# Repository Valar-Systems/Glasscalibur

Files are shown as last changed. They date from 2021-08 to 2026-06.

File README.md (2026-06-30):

# Glasscalibur — Automated Horizontal Window Opener

Glasscalibur is a smart opener for horizontal-sliding windows. A NEMA stepper
motor drives a lead screw that slides your window open and closed, controlled by
an ESP32‑C6 running [ESPHome](https://esphome.io). Control it from **any web
browser** with no app and no cloud account, pair it natively with **Home
Assistant**, or automate it with schedules, sunrise/sunset, or any system that
can send an HTTP request (Node‑RED, scripts, IFTTT‑style webhooks, etc.).

window opener main

> The video above has the top cover removed so you can see the mechanism. Under
> the cover, a custom PCB with an **ESP32‑C6** and a **TMC2209** stepper driver
> runs the motor; **limit switches** at each end of travel give the cover an
> absolute, self‑correcting position.

window opener top

---

## Features

- **Browser control, no cloud** — open `http://glasscalibur-XXXXXX.local` on
  your network and drive the cover, tune the motor, and set schedules. No Home
  Assistant or account required.
- **Native Home Assistant** — auto‑discovered over the ESPHome API as a real
  cover entity (no `command_line`/curl glue).
- **Built‑in scheduling** — open/close at fixed times **or** at sunrise/sunset
  (with minute offsets), all editable from the browser. Survives reboots.
- **Obstruction & stall protection** — TMC2209 **StallGuard** plus an
  accelerometer‑based **vibration‑stall** backstop stop the motor when the
  window jams, is locked, or something gets in the way, and save the position.
- **Over‑temperature cutoff** — an on‑board temperature sensor stops the motor
  if it exceeds 80 °C.
- **Anti‑tamper alarm** — the accelerometer flags if a mounted unit is moved or
  tilted and sounds a buzzer.
- **Over‑the‑air updates** — a one‑click **Update Firmware** button pulls the
  latest release straight from GitHub. No computer needed.
- **Instant manual override** — the whole device lifts off the window in a
  couple of seconds for cleaning or emergencies (see GIF below).

---

## How it works

Glasscalibur uses a **NEMA 17 stepper motor** connected to a **lead screw**. As
the screw turns, a nut travels along it and pushes/pulls the window sash. A
custom PCB with an **ESP32‑C6‑MINI** and a **TMC2209** silent stepper driver
runs the motor over a single‑wire UART link.

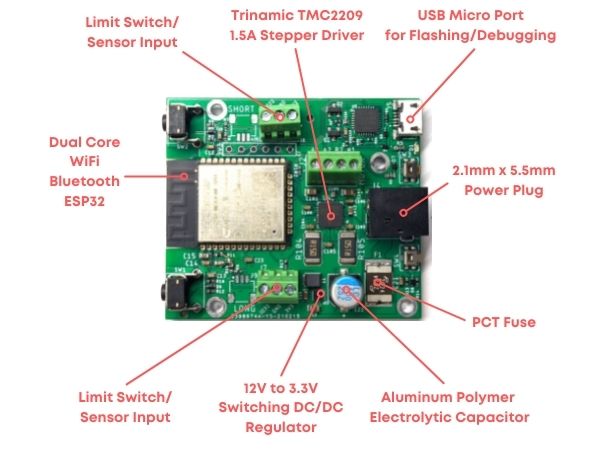
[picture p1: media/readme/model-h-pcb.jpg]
window opener PCB


Two **limit switches** — one at each end of travel — give the cover a known
absolute position: every time the carriage hits a limit, the firmware
re‑calibrates its step count, so position never drifts. The board also carries:

- a **TMP1075** temperature sensor (motor over‑temp cutoff),
- a **LIS2DH12** 3‑axis accelerometer (vibration‑stall + anti‑tamper),
- a **piezo buzzer** (tamper alarm), and
- physical buttons (a control button and a Wi‑Fi‑reset button).

The firmware is a single ESPHome configuration — see
[`firmware/esphome/`](/firmware/esphome) for the full, heavily commented config
and a flashing guide.

---

## Safety features

Safety is the primary concern with this device.

**Instant removal.** In an emergency the entire device lifts straight off the
window — no tools, a couple of seconds.

instant removal

**Obstruction & lock detection.** While moving, the cover watches for a stall
two ways: the TMC2209's StallGuard reads the motor's mechanical load, and the
accelerometer watches for the hard vibration a jammed mechanism produces. If
something gets in the way, or the window is locked, the motor stops and saves
its position. Both detectors have adjustable sensitivity so you can tune them to
your window.

**Over‑temperature cutoff.** If the motor sensor reads above 80 °C, motion stops
automatically.

**Anti‑tamper.** Once armed, the accelerometer learns the device's resting
orientation; if a mounted unit is bumped, tilted, or pried, it raises a Tamper
alert and sounds the buzzer.

---

## Will it work on your window?

Before you build or buy, check that the device fits your window. Window **sill
height** is the main factor.

### Is your window sill the correct height?

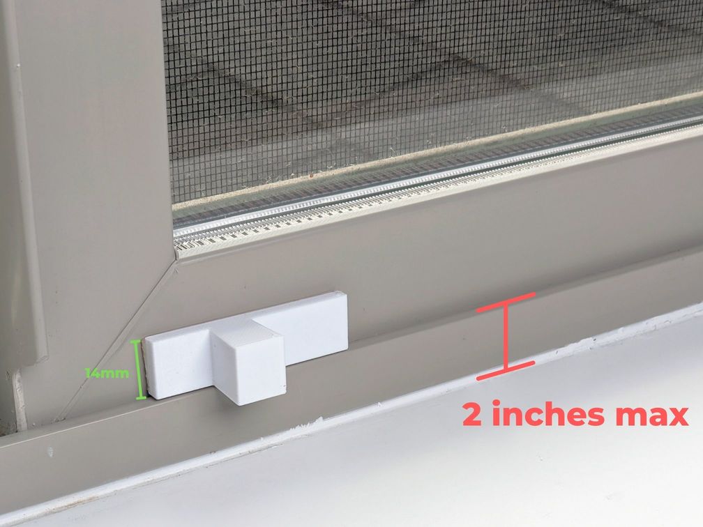
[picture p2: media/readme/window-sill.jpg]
window sill


The maximum distance from the top of the window frame to the sill is **2 inches**
(red text above). More than that and you'll need to raise the opener — a piece
of wood such as a 1×4 or 2×4 under the whole device works well.

To attach the window mount (white piece above), you need **14 mm** of the lower
sash exposed.

### Is your window wide enough?

The device is just under **22 in** end to end, so your window needs to be at
least **44 in** wide — add 2 in to be safe, so target **46 in**.

### Is your window too heavy?

The motor has been tested up to **40 lb** of window. That's very heavy and can
cause problems; if your window is that heavy, lubricate the track with dry
silicone spray first and see if that helps.

---

## Controlling it

You have several options, and they all work at once:

| Method | How |
| --- | --- |
| **Web browser** | Open `http://glasscalibur-XXXXXX.local` (the `XXXXXX` MAC suffix is printed on the USB serial log at boot). Full control panel — cover, motor tuning, schedule, diagnostics. |
| **Home Assistant** | The device is auto‑discovered over the native ESPHome API as a `cover` entity. No YAML, no curl. |
| **HTTP / REST** | The ESPHome web server exposes a REST API, e.g. `POST http://glasscalibur-XXXXXX.local/cover/glasscalibur/set?position=0.5` (position is `0.0`=closed … `1.0`=open), and `/open`, `/close`, `/stop`. Drive it from Node‑RED, scripts, or webhooks. |

### Scheduling

Two browser‑editable modes, gated by a master **Schedule Enabled** switch:

- **Fixed times** — set an **Open Time** and **Close Time**.
- **Sunrise/sunset** — turn on **Sun Schedule**, set your **latitude/longitude**,
  and optionally an open/close **offset** in minutes (e.g. `-30` to close 30 min
  before sunset).

### Home automation ideas

Home automation is where this device shines:

1. Use an indoor air‑quality sensor (e.g. Awair) to air out a stuffy room.
2. Poll PurpleAir hourly and close the window when outdoor air goes bad.
3. Compare indoor/outdoor temperature and cool the room when it helps.
4. Check a weather API and close the window when rain is forecast.
5. Open at sunrise to wake up to the birds.

Full step‑by‑step guides for all of the above live in the
[**project wiki**](https://github.com/Valar-Systems/Glasscalibur/wiki).

---

## Repository layout

| Path | Contents |
| --- | --- |
| [`firmware/esphome/`](/firmware/esphome) | **Current firmware** — the ESPHome config (`Glasscalibur-esphome.yml`) and a flashing/release guide. |
| [`firmware/arduino/`](/firmware/arduino) | Legacy Arduino firmware (the original ESPUI/HTTP build). Kept for reference. |
| [`hardware/v2.0/`](/hardware/v2.0) | 3D‑printable parts — STEP CAD files plus a ready‑to‑slice print platter (`platter-v1.3mf`). |
| [`media/`](/media) | Images and GIFs used in the docs. |

---

## How to build it

To keep it affordable, there's a kit — sourcing the screws and hardware
individually gets expensive fast.

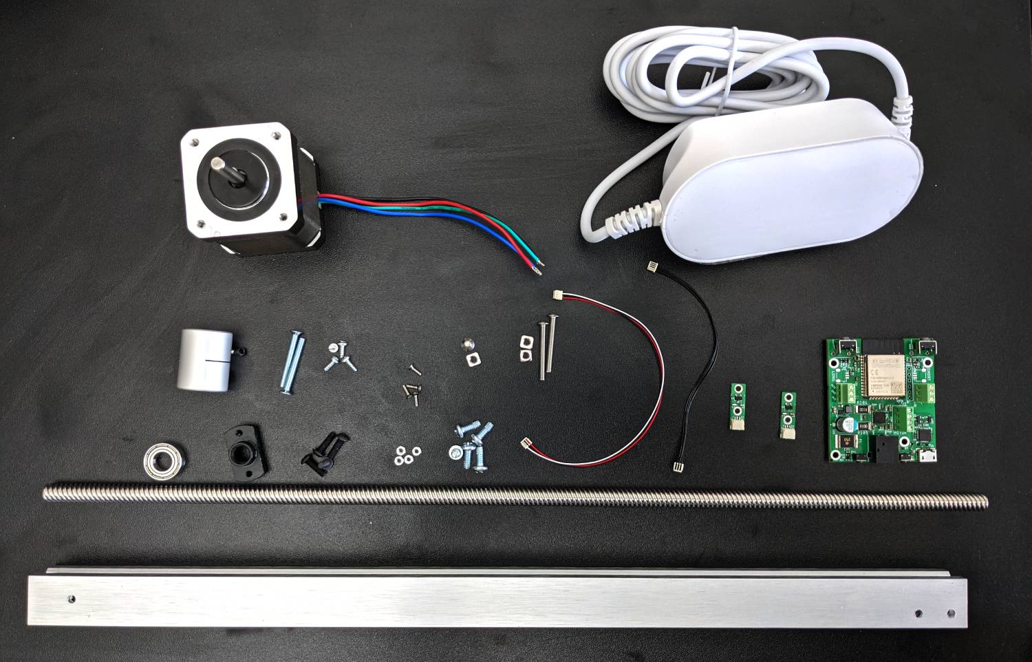
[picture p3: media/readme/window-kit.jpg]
window kit


Two kit versions are available — one with the 3D‑printed plastics and one
without (print your own):

- [Kit **excluding** 3D‑printed parts](https://valarsystems.com/products/automatic-window-opener?variant=39590892240955)
- [Kit **including** 3D‑printed parts](https://valarsystems.com/products/automatic-window-opener?variant=39590892208187)

Full assembly instructions and a build video are in the
[**Assembly Guide**](https://github.com/Valar-Systems/Glasscalibur/wiki/Assembly-Guide).

## How to 3D print it

The printable parts are in [`hardware/v2.0/`](/hardware/v2.0):

- **`platter-v1.3mf`** — a ready‑to‑slice [PrusaSlicer](https://www.prusa3d.com/prusaslicer/)
  project with the parts laid out on the bed. Print in **PETG** at **0.25 mm**
  layer height.
- The individual **`.step`** files are the CAD source for each part if you want
  to modify or re‑orient them.

See the [**3D Printing Guide**](https://github.com/Valar-Systems/Glasscalibur/wiki/3D-Printing-Guide)
for details.

## How to install it

Installation is **fast** — a few minutes of work, then a 24‑hour wait for the
adhesive to cure.

window mount

1. Attach the **window mount** (to the sash).
2. Attach the **sill mount**.
3. Wait **24 hours** for the adhesives to set, then start using the opener.

Both mounts are adhesive; if needed you can add a screw into the sill, but that
hasn't been required. Full details are in the
[**Window Installation Guide**](https://github.com/Valar-Systems/Glasscalibur/wiki/Installation-Guide).

---

## Firmware: flashing & updates

- **First flash** of a blank board is over **USB** with the ESPHome CLI
  (`esphome run firmware/esphome/Glasscalibur-esphome.yml`) or via
  [web.esphome.io](https://web.esphome.io).
- After that, update **over the air**: open the web UI → **Diagnostics** →
  **Update Firmware (GitHub)**, and the device pulls the
  [latest release](https://github.com/Valar-Systems/Glasscalibur/releases/latest)
  and reflashes itself.

The build, release, and OTA process is documented in
[`firmware/esphome/README.md`](/firmware/esphome/README.md).

---

## Documentation

The [**project wiki**](https://github.com/Valar-Systems/Glasscalibur/wiki) has
the full guides:

- [3D Printing](https://github.com/Valar-Systems/Glasscalibur/wiki/3D-Printing-Guide)
- [Assembly](https://github.com/Valar-Systems/Glasscalibur/wiki/Assembly-Guide)
- [Window Installation](https://github.com/Valar-Systems/Glasscalibur/wiki/Installation-Guide)
- [Wi‑Fi Setup](https://github.com/Valar-Systems/Glasscalibur/wiki/WiFi-Setup)
- [Web UI](https://github.com/Valar-Systems/Glasscalibur/wiki/Web-UI-Guide)
- [Motor & Stall Tuning](https://github.com/Valar-Systems/Glasscalibur/wiki/Motor-Setup)
- [Scheduling](https://github.com/Valar-Systems/Glasscalibur/wiki/Scheduling-Guide)
- [Security & Tamper](https://github.com/Valar-Systems/Glasscalibur/wiki/Security-and-Tamper)
- [API](https://github.com/Valar-Systems/Glasscalibur/wiki/API-Guide)
- [Home Assistant](https://github.com/Valar-Systems/Glasscalibur/wiki/Home-Assistant-Guide)
- [Firmware Updates](https://github.com/Valar-Systems/Glasscalibur/wiki/Firmware-Updates)

---

## License

The firmware is licensed under the **GNU GPL v3** — see
[`firmware/LICENSE`](/firmware/LICENSE).

If this project is useful to you, you can support it via
[GitHub Sponsors](https://github.com/sponsors/valar-systems).

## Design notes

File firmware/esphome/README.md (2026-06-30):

# Glasscalibur — ESPHome firmware

Wi-Fi window-cover controller (ESP32-C6 + TMC2209 stepper). Control it from any
browser at `http://glasscalibur-XXXXXX.local` (no Home Assistant required), or
pair it with Home Assistant over the native ESPHome API.

The full config lives in [`Glasscalibur-esphome.yml`](Glasscalibur-esphome.yml);
every setting is documented inline in that file.

## Web UI

Open `http://glasscalibur-XXXXXX.local` (the `XXXXXX` MAC suffix is printed on
the serial log at boot). Entities are organized into collapsible groups:

| Group | What's in it |
| --- | --- |
| **Control** | The cover, its live State, and Button 1 |
| **Motion Tuning** | Speed, acceleration, IRUN (motor current) |
| **StallGuard / Stall Detection** | StallGuard + the accelerometer vibration-stall backstop and their thresholds |
| **Security / Tamper** | Tamper detection, threshold, baseline / clear buttons |
| **Schedule** | Fixed open/close times **or** sunrise/sunset, timezone, location |
| **Diagnostics** | Firmware version, **Update Firmware**, **Restart**, temps, Wi-Fi, lifetime counters |

## Scheduling

Two mutually-exclusive modes, both gated by the master **Schedule Enabled** switch:

- **Fixed times** (default): set **Open Time** / **Close Time**.
- **Sunrise/sunset**: turn on **Sun Schedule**, set **Latitude** / **Longitude**,
  and optionally **Sun Open Offset** / **Sun Close Offset** (minutes, signed — e.g.
  `-30` closes 30 min before sunset). Requires a network connection for SNTP time.

## Updating the firmware

Two ways to update once the device is already running this firmware:

- **Over the air, from the device:** open the web UI → **Diagnostics** →
  **Update Firmware (GitHub)**. The device downloads the latest release straight
  from GitHub, flashes itself, and reboots — no computer needed (requires an
  internet connection).
- **Manually:** push a new build with the ESPHome CLI/dashboard
  (`esphome run Glasscalibur-esphome.yml`, pick the network/OTA target), or
  upload the `*.ota.bin` in the device's own **OTA Update** web card.

> The very first flash of a blank chip must be over USB (`esphome run` with the
> serial port) — there's no firmware yet to receive an OTA.

## Publishing a release (maintainers)

The **Update Firmware (GitHub)** button downloads, from this repo's
[latest release](https://github.com/Valar-Systems/Glasscalibur/releases/latest):

```
https://github.com/Valar-Systems/Glasscalibur/releases/latest/download/Glasscalibur.ota.bin
https://github.com/Valar-Systems/Glasscalibur/releases/latest/download/Glasscalibur.ota.bin.md5
```

The asset names are **version-less and stable** (`${ota_asset}` in the YAML, =
`Glasscalibur`) so this `latest/download/` URL never changes. To cut a release:

1. **Bump the version.** Edit `firmware_version` in `Glasscalibur-esphome.yml`
   (it feeds both `project.version` and the *Firmware Version* sensor).
2. **Build the OTA image:**
   ```bash
   esphome compile Glasscalibur-esphome.yml
   ```
   ESPHome writes the OTA image to
   `.esphome/build/glasscalibur/.pioenvs/glasscalibur/firmware.ota.bin`.
3. **Stage the assets with stable names:**
   ```bash
   cp .esphome/build/glasscalibur/.pioenvs/glasscalibur/firmware.ota.bin Glasscalibur.ota.bin
   md5sum Glasscalibur.ota.bin | awk '{print $1}' > Glasscalibur.ota.bin.md5
   ```
   (`md5sum` on Linux/Git-Bash; `md5 -q` on macOS. The `.md5` file must contain
   just the 32-char hex digest — the OTA flash checks the image against it.)
4. **Create a GitHub release** (tag e.g. `v1.1.0`), attach `Glasscalibur.ota.bin`
   and `Glasscalibur.ota.bin.md5`, and make sure it's marked **Latest**.

Until at least one such release exists, the button logs a download error and
leaves the running firmware untouched — it never bricks the device.

> **Tip:** also flash a brand-new board over USB without compiling by attaching
> a `Glasscalibur.factory.bin` (`esphome compile` produces `firmware.factory.bin`
> in the same build folder) and flashing it via [web.esphome.io](https://web.esphome.io).

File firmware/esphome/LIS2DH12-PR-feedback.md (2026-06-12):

# LIS2DH12 PR — priorities from a real deployment

Feedback for the in-flight LIS2DH12 PR (esphome#14788) based on production use
of the component on an ESP32-C6 device alongside a stepper driver, I²C
temperature sensor, GPIO buttons, and several interval blocks.

---

## Top priorities, ranked

### 1. Stop blocking the main loop in `update()`

The current synchronous DRDY-polling loop produces this on every read:

```
[W][component:522]: lis2dh12_base took a long time for an operation (174 ms), max is 30 ms
```

This is the single biggest issue and is covered in detail below.

### 2. Expose hardware interrupts in YAML

The chip's killer features for ESPHome users are the INT1/INT2 sources:
activity/inactivity (wake-up threshold), 6D/4D orientation, single/double-tap,
free-fall. Mapping these to `binary_sensor` children would obsolete a lot of
polling-based application code. Even just **activity + 6D orientation** would
cover the majority of use cases (motion-triggered tasks, tamper detection,
tilt detection).

### 3. Expose the embedded high-pass filter (CTRL_REG2)

Lets the chip subtract DC gravity in hardware so the output IS the AC /
vibration component. Removes the need for `|sqrt(x² + y² + z²) − 1g|`
gymnastics in user lambdas, and makes the downstream interrupt thresholds
(#2 above) work on filtered data instead of raw.

### 4. FIFO mode (32-sample burst)

One I²C transaction per ~30 samples instead of one per sample. Eliminates the
per-sample DRDY-poll overhead entirely and lets people sample at high ODR
without saturating the bus.

### 5. Quieter default logging

Currently emits ~50 `i2c.idf` lines per accelerometer read at DEBUG — drowns
the bus log for anyone debugging other components. Move the per-register
transaction chatter to VERBOSE and keep DEBUG limited to state changes (ODR
set, range set, interrupt fired, etc.).

### 6. Stable YAML schema before merge

I'm pinned to a commit SHA in production because the schema can shift between
pushes. A short "schema is frozen for the merge" signal would let me drop the
SHA pin.

**If time-constrained:**

- Do only one → **#1 (main-loop blocking)**. By far the most painful in real
  deployments because it perturbs every other component on the device.
- Do two → add **#2 (interrupts)**. That's the feature gap that keeps the
  polling architecture relevant in the first place.

The rest (auto-address detect, self-test mode, sleep mode) are nice-to-haves
and not worth listing if you're time-constrained.

---

## Deep dive on #1 — main-loop blocking

### What's actually happening

ESPHome runs as a cooperative single-threaded main loop on ESP32 — every
component's `loop()` and `update()` execute back-to-back on the same task.
A "loop tick" is normally ~16 ms. When one component blocks, nothing else
gets to run: button polling, sensor publishes, interval blocks, cover state
transitions — all stalled.

The current `lis2dh12_base::update()` looks (functionally) like this:

```cpp
void update() override {
  // Spin on the data-ready bit until the chip says new data is ready
  while (!(read_register(STATUS_REG) & ZYXDA_MASK)) {
    // busy wait — every iteration is one I²C transaction (~1-3 ms)
  }
  uint8_t buf[6];
  read_burst(OUT_X_L | AUTO_INC, buf, 6);
  publish_x_y_z(buf);
}
```

That `while` loop is the killer. You can see it in the raw bus log — dozens of
`0x18 TX 39 RX ..` (status reads) before the final `0x18 TX A8 RX ..` (the
6-byte X/Y/Z burst).

### Why 174 ms is bad

- The main-loop watchdog warning (`max is 30 ms`) is the visible symptom, but
  the real cost is **other components getting starved**. 174 ms = ~10 missed
  main-loop iterations.
- Anything timing-sensitive on the main loop suffers: GPIO debounce filters
  can miss edges, interval blocks fire late, motion-completion polls run
  with jitter close to their own period.
- The stepper isn't affected on my board — `tmc2209` runs the actual step
  generation on a dedicated FreeRTOS task. So the motor keeps moving smoothly,
  but the supervisor logic around it lags.
- The blocking time is **variable**. It depends on where in the chip's sample
  cycle the `update()` call happened to land, plus any I²C contention from
  other devices on the bus. So 174 ms one time, 50 ms next, 300 ms
  occasionally — unpredictable jitter is worse for the overall system than a
  steady delay would be.

### The three fixes, ranked

**1. DRDY-interrupt-driven (the right answer)**

The chip has `CTRL_REG3.I1_ZYXDA`; set it and INT1 asserts the instant new
XYZ data is available. Component config takes an `interrupt_pin:`; an ISR
sets a `volatile bool data_ready` flag; `loop()` (not `update()`) checks
the flag and only then issues the burst read. Net cost per sample: ~one
6-byte I²C transaction (~1.5 ms), latency from chip-ready to publish is
sub-millisecond. Zero polling, zero blocking.

```cpp
void setup() override {
  write_register(CTRL_REG3, I1_ZYXDA);             // route DRDY → INT1
  attachInterrupt(int_pin_, isr_, RISING);
}
void loop() override {
  if (!data_ready_) return;
  data_ready_ = false;
  uint8_t buf[6];
  read_burst(OUT_X_L | AUTO_INC, buf, 6);
  publish_x_y_z(buf);
}
```

**2. Skip-and-retry (acceptable fallback for users who don't wire INT1)**

`update()` reads STATUS *once*. If `ZYXDA == 0`, return immediately and try
again next tick. The penalty is that occasional ticks publish nothing —
completely fine because the application either polls cached values at its
own cadence anyway, or wants new-data-or-nothing semantics (also fine).

```cpp
void update() override {
  if (!(read_register(STATUS_REG) & ZYXDA_MASK)) return;
  uint8_t buf[6];
  read_burst(OUT_X_L | AUTO_INC, buf, 6);
  publish_x_y_z(buf);
}
```

This alone eliminates the warning. Single STATUS read = ~1.5 ms, comfortably
under 30 ms.

**3. Yield between polls (worst of the three, but better than nothing)**

Call `App::feed_wdt()` and a brief `delay(0)` / `taskYIELD()` between status
polls. Doesn't actually unblock the main loop — other components still wait —
but the hardware watchdog and the IDF task scheduler get to run. This is
what you do when you can't change the polling architecture. Avoid if the
other two are feasible.

### Recommended path

**#2 immediately** — one-line change, fixes the warning for everyone.

**#1 as the proper long-term solution** — optional `interrupt_pin:` config,
gated on whether the user wired INT1. Both can coexist: interrupt mode when
configured, skip-and-retry when not.

ESPHome's `LIS3DH` integration (different chip, related family) uses the
skip-and-retry pattern and doesn't have this problem — there's an in-tree
precedent to reference.

### Why this matters beyond cosmetics

Anyone building real applications on the chip — door/window sensors, vibration
monitors, anti-tamper systems — is going to mix it with other components. A
174 ms hiccup every 200 ms means the chip is effectively unusable alongside
fast button debouncing, hardware-timer-driven outputs, or any other timing-
sensitive logic. Right now the only safe deployments are ones where LIS2DH12
is the *only* time-sensitive thing on the device.

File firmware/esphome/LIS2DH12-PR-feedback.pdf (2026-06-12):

# LIS2DH12 PR — priorities from a real deployment

Feedback for the in-flight LIS2DH12 PR (esphome#14788) based on production use of the component on an ESP32-C6 device alongside a stepper driver, I²C temperature sensor, GPIO buttons, and several interval blocks.

## Top priorities, ranked

### 1. Stop blocking the main loop in update()

The current synchronous DRDY-polling loop produces this on every read:

[W][component:522]: lis2dh12_base took a long time for an operation (174 ms), max is 30

This is the single biggest issue and is covered in detail below.

### 2. Expose hardware interrupts in YAML

The chip's killer features for ESPHome users are the INT1/INT2 sources: activity/inactivity (wake-up threshold), 6D/4D orientation, single/double-tap, free-fall. Mapping these to binary_sensor children would obsolete a lot of polling-based application code. Even just activity + 6D orientation would cover the majority of use cases (motion-triggered tasks, tamper detection, tilt detection).

### 3. Expose the embedded high-pass filter (CTRL_REG2)

Lets the chip subtract DC gravity in hardware so the output IS the AC / vibration component. Removes the need for |sqrt(x² + y² + z²) − 1g| gymnastics in user lambdas, and makes the downstream interrupt thresholds (#2 above) work on filtered data instead of raw.

### 4. FIFO mode (32-sample burst)

One I²C transaction per ~30 samples instead of one per sample. Eliminates the per-sample DRDY-poll overhead entirely and lets people sample at high ODR without saturating the bus.

### 5. Quieter default logging

Currently emits ~50 i2c.idf lines per accelerometer read at DEBUG — drowns the bus log for anyone debugging other components. Move the per-register transaction chatter to VERBOSE and keep DEBUG limited to state changes (ODR set, range set, interrupt fired, etc.).

### 6. Stable YAML schema before merge

I'm pinned to a commit SHA in production because the schema can shift between pushes. A short "schema is frozen for the merge" signal would let me drop the SHA pin.
If time-constrained:

Do only one → #1 (main-loop blocking). By far the most painful in real deployments because it perturbs every other component on the device.
Do two → add #2 (interrupts). That's the feature gap that keeps the polling architecture relevant in the first place.

The rest (auto-address detect, self-test mode, sleep mode) are nice-to-haves and not worth listing if you're time-constrained.

## Deep dive on #1 — main-loop blocking

### What's actually happening

ESPHome runs as a cooperative single-threaded main loop on ESP32 — every component's loop() and update() execute back-to-back on the same task. A "loop tick" is normally ~16 ms. When one component blocks, nothing else gets to run: button polling, sensor publishes, interval blocks, cover

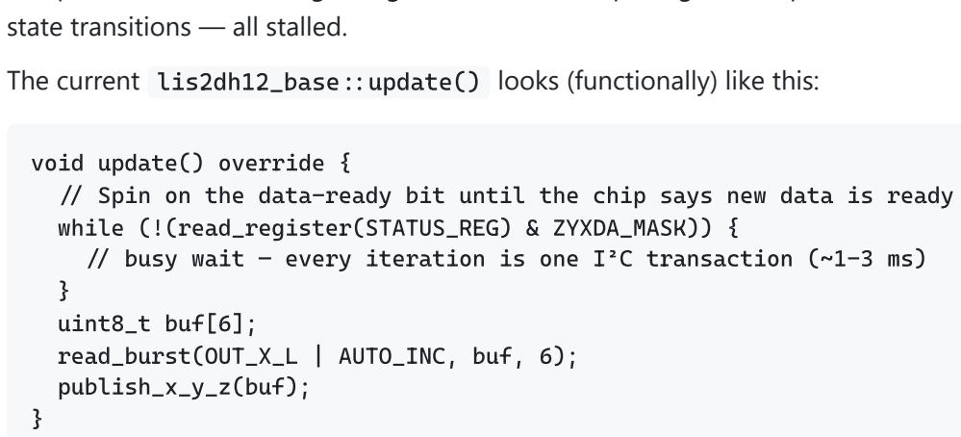
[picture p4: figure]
state transitions — all stalled.; void update() override {; while (!(read_register(STATUS_REG) & ZYXDA_MASK)) {; uint8_t buf[6];; read_burst(OUT_X_L | AUTO_INC, buf, 6);; publish_x_y_z(buf);

The current lis2dh12_base: update() looks (functionally) like this:

/ Spin on the data-ready bit until the chip says new data is ready

/ busy wait — every iteration is one I²C transaction (~1-3 ms)

That while loop is the killer. You can see it in the raw bus log — dozens of 0x18 TX 39 RX . (status reads) before the final 0x18 TX A8 RX . (the 6-byte X/Y/Z burst).

### Why 174 ms is bad

The main-loop watchdog warning ( max is 30 ms ) is the visible symptom, but the real cost is other components getting starved. 174 ms = ~10 missed main-loop iterations.
Anything timing-sensitive on the main loop suffers: GPIO debounce filters can miss edges, interval blocks fire late, motion-completion polls run with jitter close to their own period.
The stepper isn't affected on my board — tmc2209 runs the actual step generation on a dedicated FreeRTOS task. So the motor keeps moving smoothly, but the supervisor logic around it lags.
The blocking time is variable. It depends on where in the chip's sample cycle the update() call happened to land, plus any I²C contention from other devices on the bus. So 174 ms one time, 50 ms next, 300 ms occasionally — unpredictable jitter is worse for the overall system than a steady delay would be.

### The three fixes, ranked

### 1. DRDY-interrupt-driven (the right answer)

The chip has CTRL_REG3.I1_ZYXDA ; set it and INT1 asserts the instant new XYZ data is available. Component config takes an interrupt_pin: ; an ISR sets a volatile bool data_ready flag; loop() (not update() ) checks the flag and only then issues the burst read. Net cost per sample: ~one 6-byte I²C transaction (~1.5 ms), latency from chip-ready to publish is sub-millisecond. Zero

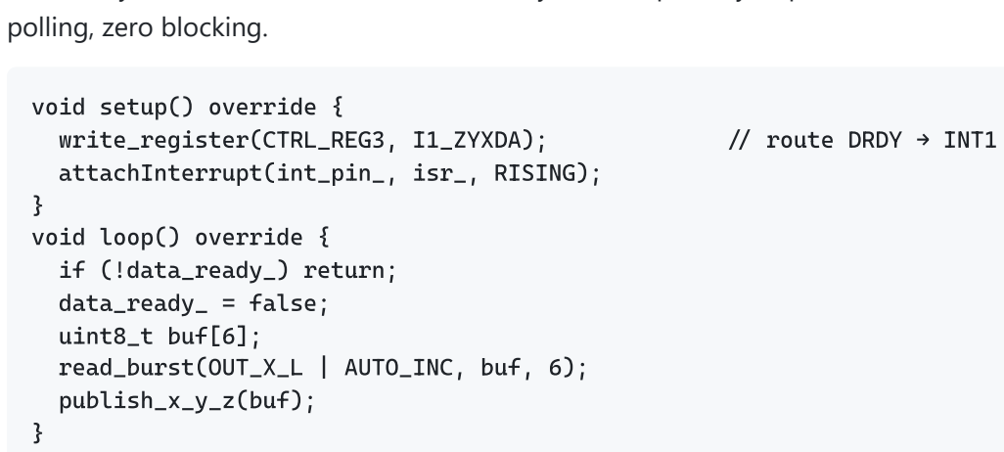
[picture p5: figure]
polling, zero blocking.; void setup() override {; write_register(CTRL_REG3, I1_ZYXDA);; / route DRDY → INT1; attachInterrupt(int_pin_, isr_, RISING);; void loop() override {; if (!data_ready_) return;; data_ready_ = false;; uint8_t buf[6];; read_burst(OUT_X_L | AUTO_INC, buf, 6);; publish_x_y_z(buf);

### 2. Skip-and-retry (acceptable fallback for users who don't wire INT1)

update() reads STATUS once. If ZYXDA = 0 , return immediately and try again next tick. The penalty is that occasional ticks publish nothing — completely fine because the application either polls cached values at its own cadence anyway, or wants new-data-or-nothing semantics (also fine).

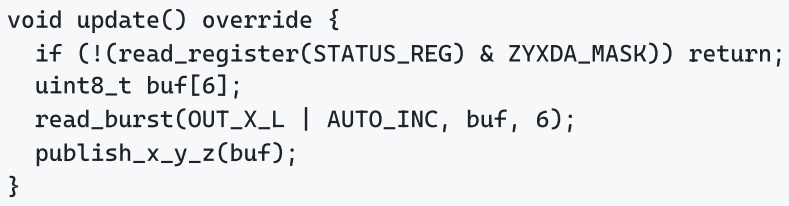
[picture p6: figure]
void update() override {; if (!(read_register(STATUS_REG) & ZYXDA_MASK)) return;; uint8_t buf[6];; read_burst(OUT_X_L | AUTO_INC, buf, 6);; publish_x_y_z(buf);

This alone eliminates the warning. Single STATUS read = ~1.5 ms, comfortably under 30 ms.

### 3. Yield between polls (worst of the three, but better than nothing)

Call App: feed_wdt() and a brief delay(0) / taskYIELD() between status polls. Doesn't actually unblock the main loop — other components still wait — but the hardware watchdog and the IDF task scheduler get to run. This is what you do when you can't change the polling architecture. Avoid if the other two are feasible.

### Recommended path

#2 immediately — one-line change, fixes the warning for everyone.

#1 as the proper long-term solution — optional interrupt_pin: config, gated on whether the user wired INT1. Both can coexist: interrupt mode when configured, skip-and-retry when not. ESPHome's LIS3DH integration (different chip, related family) uses the skip-and-retry pattern and doesn't have this problem — there's an in-tree precedent to reference.

### Why this matters beyond cosmetics

Anyone building real applications on the chip — door/window sensors, vibration monitors, anti-tamper systems — is going to mix it with other components. A 174 ms hiccup every 200 ms means the chip is effectively unusable alongside fast button debouncing, hardware-timer-driven outputs, or any other timing- sensitive logic. Right now the only safe deployments are ones where LIS2DH12 is the only time-sensitive thing on the device.

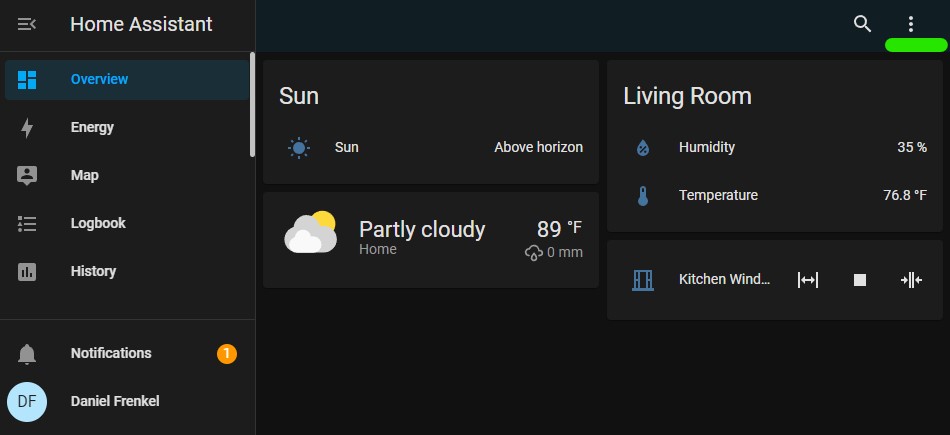
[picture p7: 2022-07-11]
media/docs/edit-ui.jpg

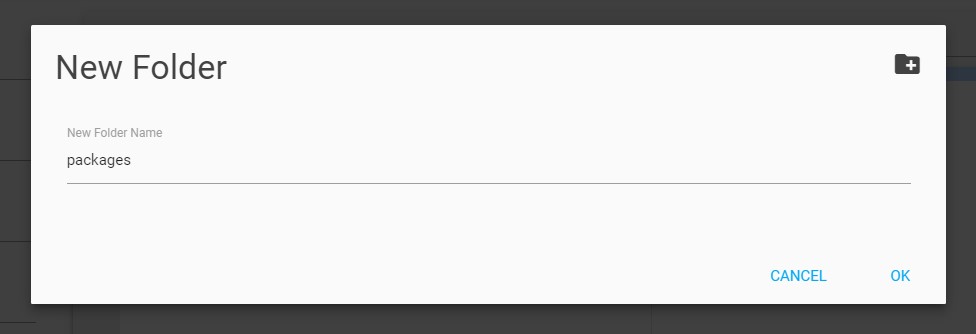
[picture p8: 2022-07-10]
media/docs/packages-folder.jpg

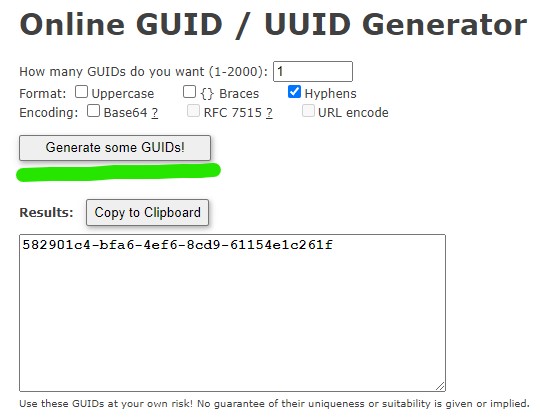
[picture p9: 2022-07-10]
media/docs/generate-guid.jpg

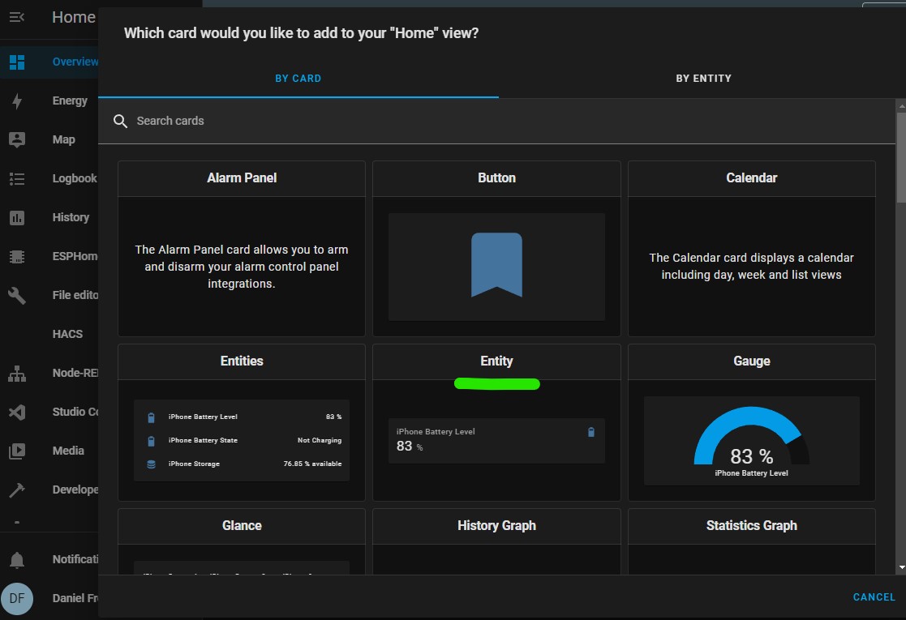
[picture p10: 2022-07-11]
media/docs/select-entities.jpg

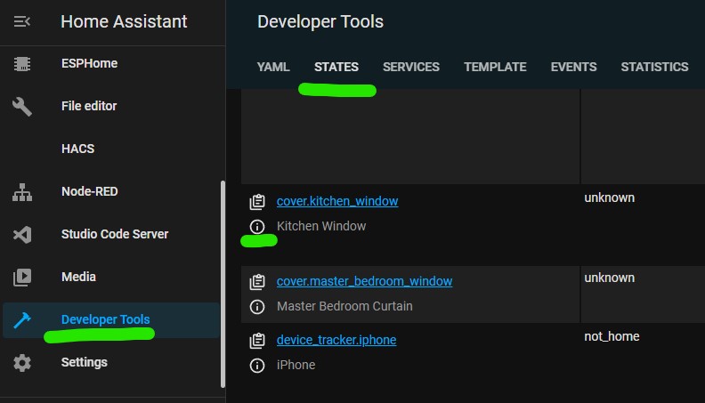
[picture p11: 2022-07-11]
media/docs/states.jpg

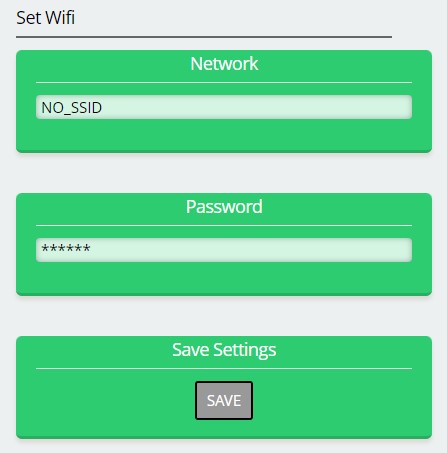
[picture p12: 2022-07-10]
media/docs/wifi-tab.jpg

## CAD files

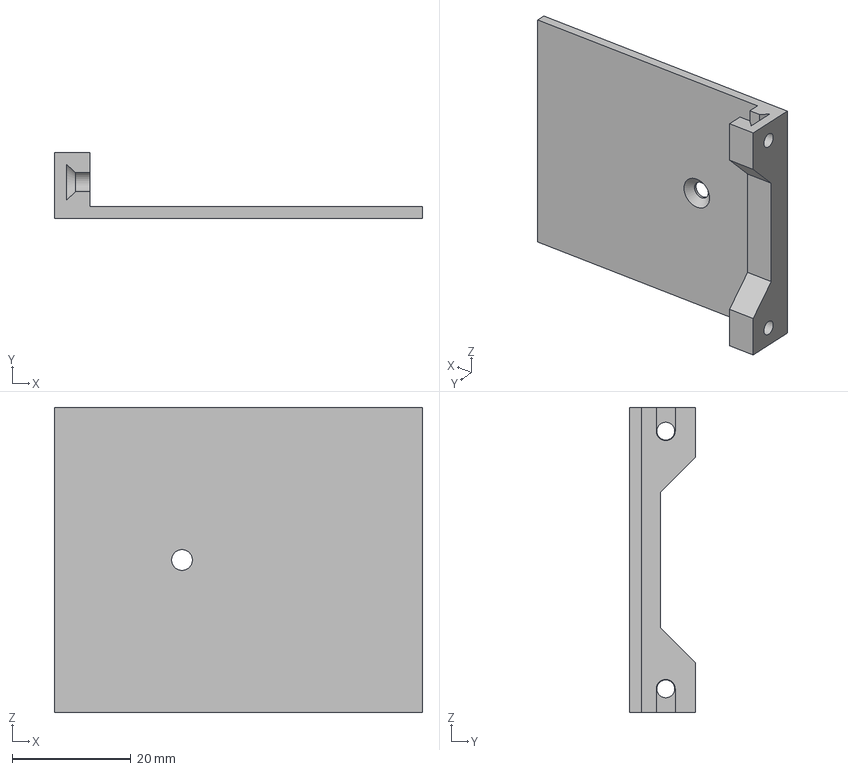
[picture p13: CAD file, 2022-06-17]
hardware/Plastics/open-left/400mm/STLs/MH1.3mf
61.9 x 11.1 x 51.4 mm

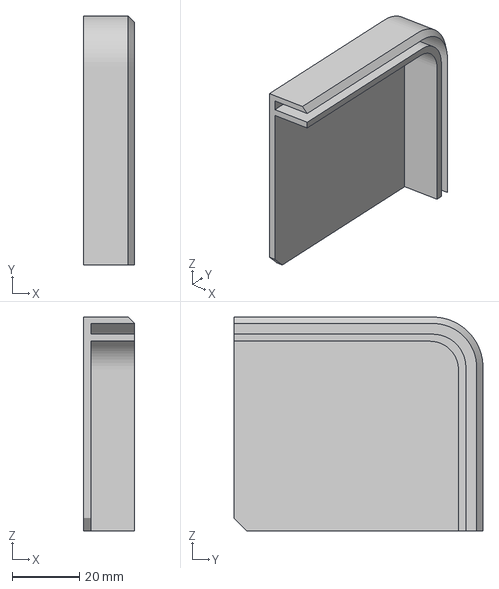
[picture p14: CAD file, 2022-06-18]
hardware/Plastics/open-left/500mm/STLs/MH4.3mf
15.2 x 74.2 x 63.7 mm

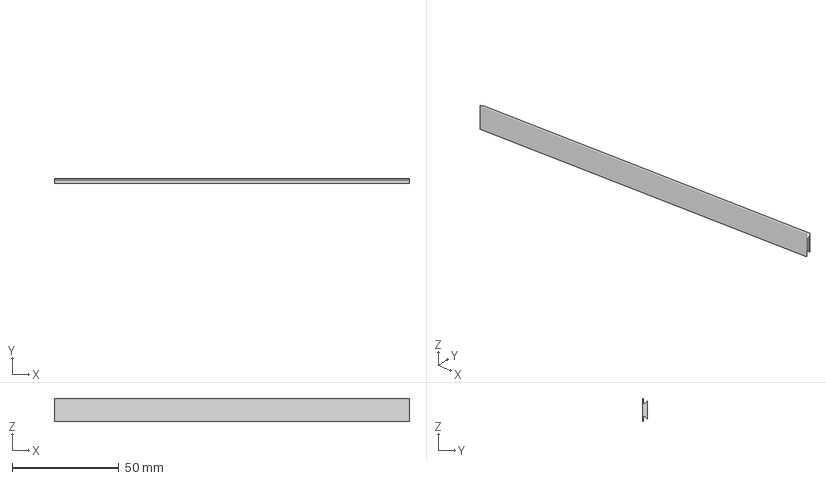
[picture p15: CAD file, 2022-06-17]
hardware/Plastics/open-left/STLs/MH18-500mm.3mf
166.0 x 2.40 x 10.8 mm

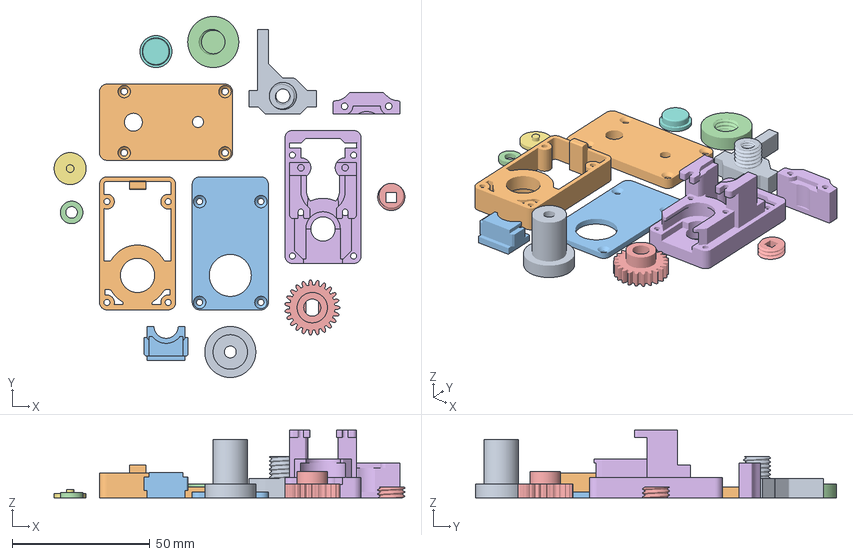
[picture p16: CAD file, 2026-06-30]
hardware/v2.0/platter-v1.3mf
127.1 x 130.8 x 24.6 mm
wall-connector
back-plate
bearing-holder
lead-screw-gear-1
lead-screw-gear-2
motor-housing-top
button-small
button-big
screw-pusher
front-plate-1
front-plate-2
screw-wall-connector
internal-screw-cap
motor-housing-bottom

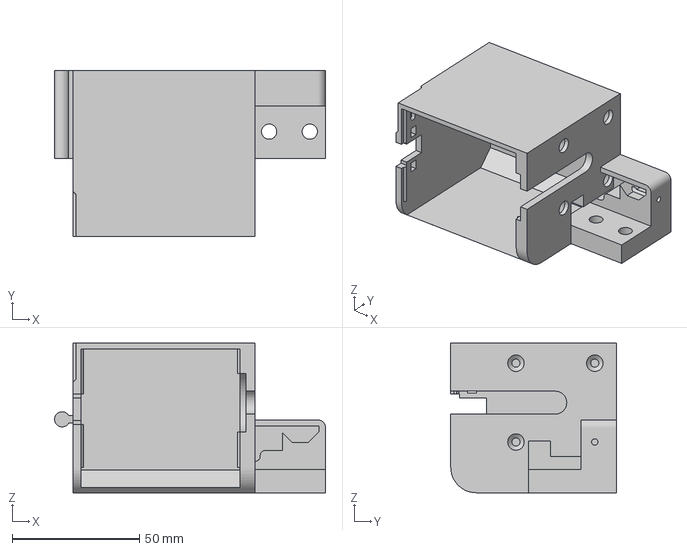
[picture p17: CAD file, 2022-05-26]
hardware/Plastics/open-left/400mm/STLs/MH5.3mf
106.6 x 65.1 x 58.8 mm

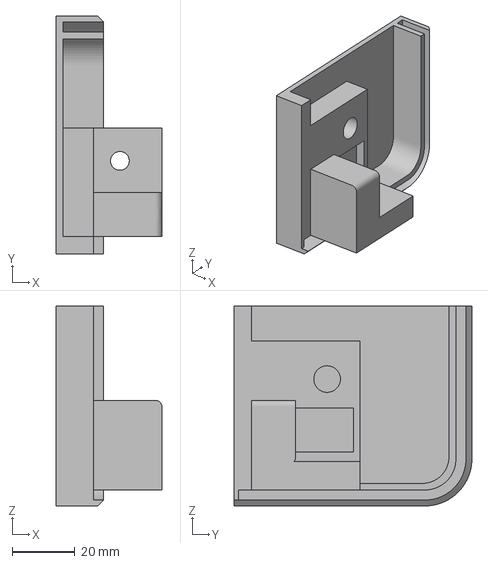
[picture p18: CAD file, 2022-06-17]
hardware/Plastics/open-left/500mm/STLs/MH9.3mf
33.8 x 75.8 x 63.7 mm

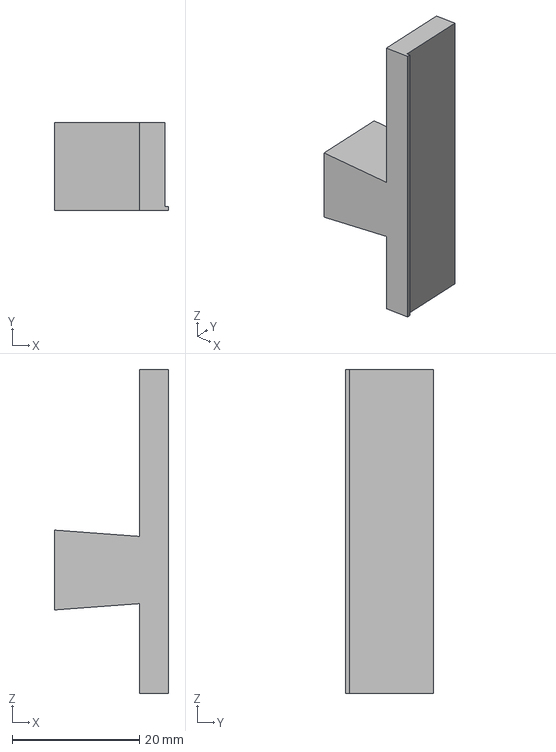
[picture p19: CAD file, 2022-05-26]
hardware/Plastics/open-left/400mm/STLs/MH16.3mf
18.0 x 13.8 x 51.0 mm

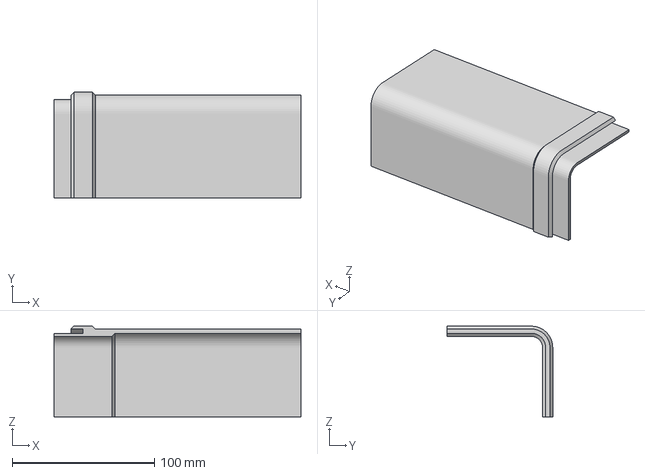
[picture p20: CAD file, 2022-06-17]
hardware/Plastics/open-left/500mm/STLs/MH12.3mf
173.6 x 74.2 x 63.7 mm

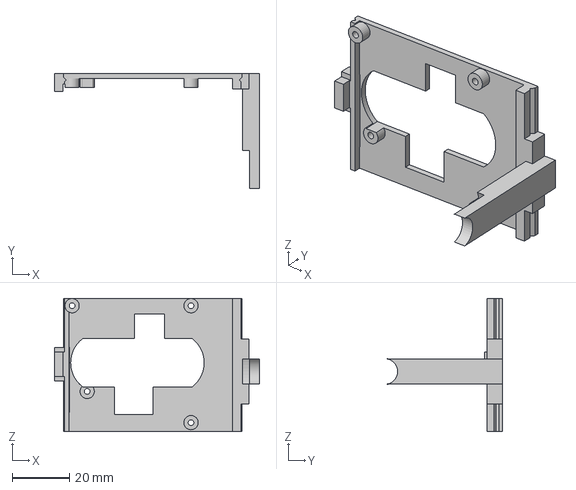
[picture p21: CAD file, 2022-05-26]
hardware/Plastics/open-left/400mm/STLs/MH6.3mf
71.5 x 40.2 x 46.6 mm

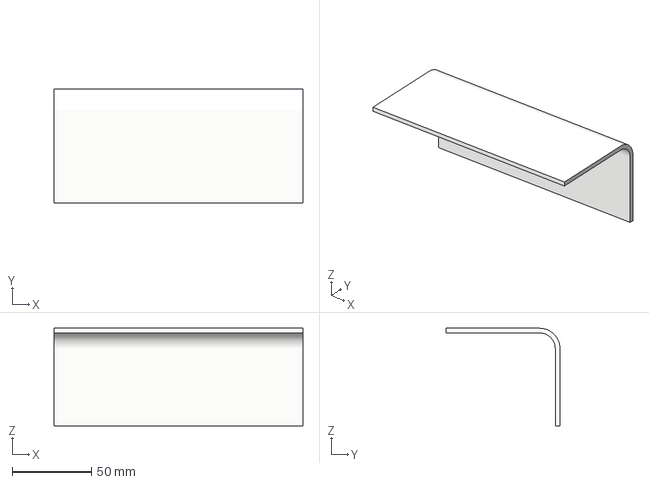
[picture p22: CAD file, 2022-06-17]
hardware/Plastics/open-left/500mm/STLs/MH10.3mf
157.5 x 72.2 x 61.7 mm

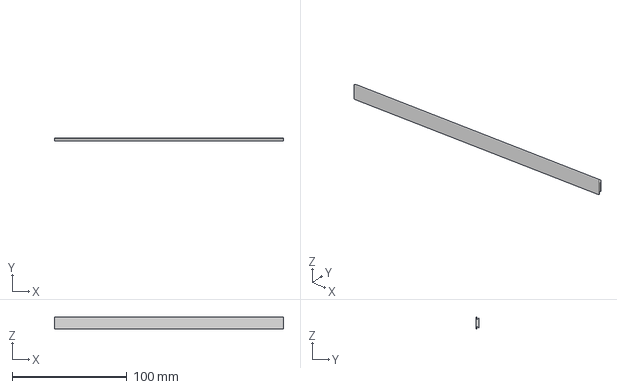
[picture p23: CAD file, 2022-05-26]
hardware/Plastics/open-left/STLs/MH14-400mm.3mf
200.0 x 2.40 x 10.8 mm

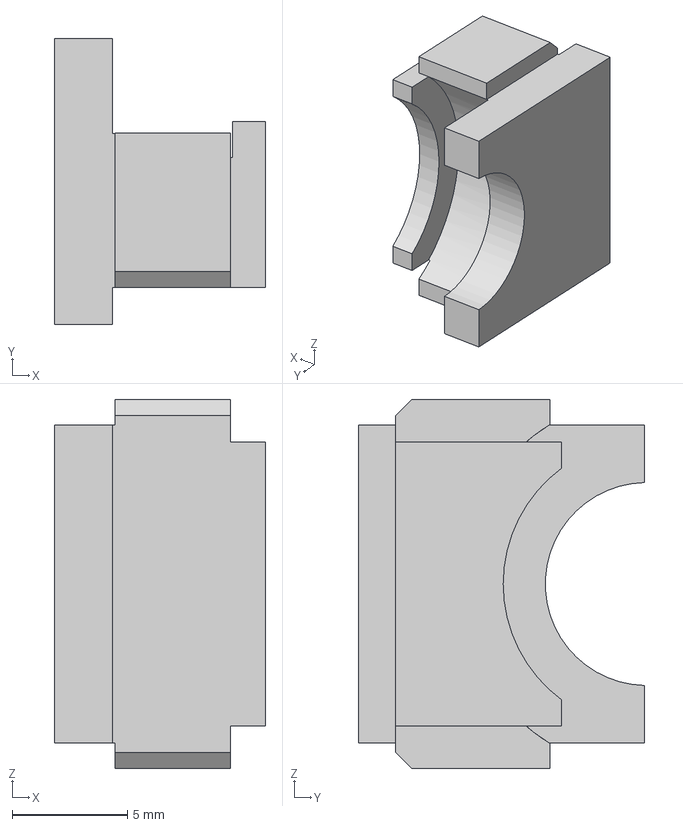
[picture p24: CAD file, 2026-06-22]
hardware/v2.0/bearing-holder.step
9.15 x 12.4 x 16.0 mm

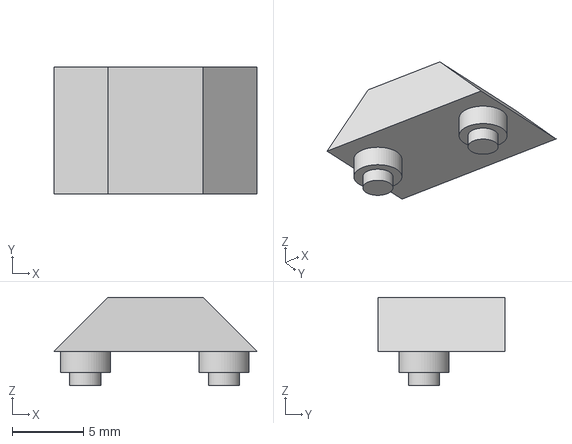
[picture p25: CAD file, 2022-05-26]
hardware/Plastics/open-left/400mm/STLs/MH8.3mf
14.2 x 8.87 x 6.20 mm

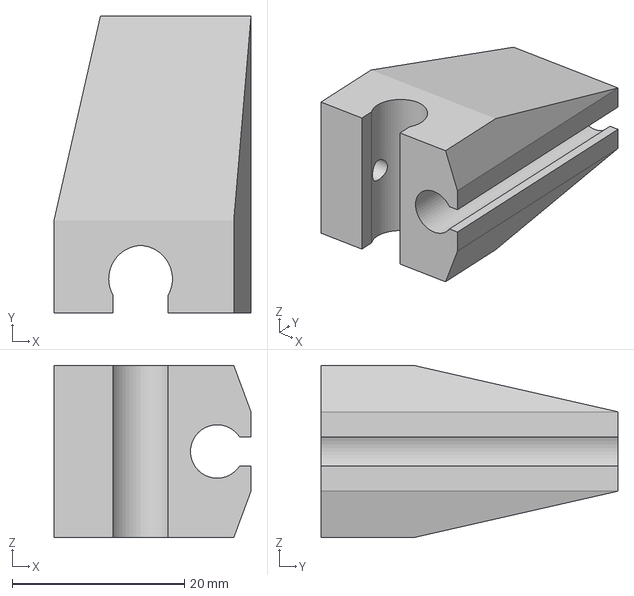
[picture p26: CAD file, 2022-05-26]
hardware/Plastics/open-left/400mm/STLs/MH3.3mf
22.9 x 34.4 x 20.0 mm

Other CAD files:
hardware/Plastics/open-left/STLs/MH13-500mm.3mf
hardware/Plastics/open-left/STLs/MH14-500mm.3mf
hardware/Plastics/open-left/500mm/STLs/MH11.3mf
hardware/Plastics/open-left/STLs/MH13-400mm.3mf
hardware/Plastics/open-left/400mm/STLs/MH7.3mf
hardware/v2.0/aligner-tool.step
hardware/v2.0/back-plate.step
hardware/v2.0/button-big.step
hardware/v2.0/button-small.step
hardware/v2.0/front-plate-1.step
hardware/v2.0/front-plate-2.step
hardware/v2.0/internal-screw-cap.step
hardware/v2.0/lead-screw-gear-1.step
hardware/v2.0/lead-screw-gear-2.step
hardware/v2.0/motor-housing-bottom.step
hardware/v2.0/motor-housing-top.step
hardware/v2.0/screw-pusher.step
hardware/v2.0/screw-wall-connector.step
hardware/v2.0/wall-connector.step
hardware/v2.0/wall-mount.step

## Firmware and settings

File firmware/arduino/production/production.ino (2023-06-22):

#include <Arduino.h>
#include <ESPUI.h>
#include <ezTime.h>
#include <FastAccelStepper.h>
#include <HardwareSerial.h>
#include <TMCStepper.h>
#include <SPI.h>
#include <Preferences.h>
#include <SimpleFOC.h>
#include <SimpleFOCDrivers.h>
#include "encoders/mt6835/MagneticSensorMT6835.h"
#include "Memory.h"
#include "ResetButton.h"
#include "MotorControl.h"
#include "API.h"
#include "calibration.h"
#include "ESPUI.h"


// the setup function runs once when you press reset or power the board
void setup() {

  Serial.begin(115200);
  delay(1000);
  preferences.begin("local", false);
  load_preferences();
  setup_motors();
  API();
  ESPUIsetup();


  // Now set up tasks to run independently.
  xTaskCreatePinnedToCore(
    MotorTaskCode, //Motor Task
    "MotorTask",   // A name just for humans
    1024 * 4, // This stack size can be checked & adjusted by reading the Stack Highwater
    NULL,
    3,  // Priority, with 3 (configMAX_PRIORITIES - 1) being the highest, and 0 being the lowest.
    &MotorTask, //Task Handle
    1);

  xTaskCreatePinnedToCore(
    ButtonTaskCode, //Motor Task
    "ButtonTask",   // A name just for humans
    1024 * 4, // This stack size can be checked & adjusted by reading the Stack Highwater
    NULL,
    1,  // Priority, with 3 (configMAX_PRIORITIES - 1) being the highest, and 0 being the lowest.
    &ButtonTask, //Task Handle
    0);

}

void loop()
{
  // Empty. Things are done in Tasks.

}

/*--------------------------------------------------*/
/*---------------------- Tasks ---------------------*/
/*--------------------------------------------------*/

void ButtonTaskCode(void *pvParameters)  // Motor Task
{
  (void) pvParameters;

  for (;;)
  {

    if (btn1Press == 1) {

      if (run_motor == true && move_to_step == max_steps) {
        stepper->forceStop();
        move_to_step = 0;
        stepper->moveTo(move_to_step);
      }

      else if (run_motor == true && move_to_step == 0 )
      {
        stepper->forceStop();
        delay(100);
        move_to_step = stepper->getCurrentPosition();
        stepper->moveTo(move_to_step);
      }
      else
      {
        move_to_step = 0;
        run_motor = true;
      }
    }

    if (btn2Press == 1) {

      if (run_motor == true && move_to_step == 0) {
        stepper->forceStop();
        move_to_step = max_steps;
        stepper->moveTo(move_to_step);
      }

      else if (run_motor == true && move_to_step == max_steps )
      {
        stepper->forceStop();
        delay(100);
        move_to_step = stepper->getCurrentPosition();
        stepper->moveTo(move_to_step);
      }
      else
      {
        move_to_step = max_steps;
        run_motor = true;
      }
    }

    if (run_motor == true)
    {
      int loadAngle = 255;
      int loadTrip = 0;
      delay(300); // only delay one time
      Serial.println("Starting Detection");
      while (run_motor == true)
      {

        Serial.println(driver.SG_RESULT());
        loadAngle = driver.SG_RESULT();
        if (loadAngle <= 0)
        {
          Serial.println("SG 0");
          loadTrip++;
          loadAngle = 255;
        }

        if (loadTrip >= 2)
        {

          //stalled_motor = true;
          break;
        }
      }
    }
    else
    {
      vTaskDelay(1);
    }
  }
}


void MotorTaskCode(void *pvParameters)  // Motor Task
{
  (void) pvParameters;

  for (;;)
  {
    if (run_motor == true)
    {
      Serial.println("Run Motor Function");
      move_motor();
      run_motor = false;
      stalled_motor = false; // Reset Stall flag
      ESPUI.updateLabel(positionLabel, String(int(((float)current_position / (float)max_steps) * 100)));
      Serial.println("Motor Complete");
    }
    else if (calibrate == 1)
    {
      TravelDistance();
      CalibrateCurrent();
      ESPUI.updateNumber(currentMax, current);
      CalibrateStall();
      ESPUI.updateNumber(stallMax, stall);
      calibrate = 0;
    }
    else if (close_pos == 1)
    {
      ClosePosition();
      close_pos = 0;
    }
    else if (wifi_button == true)
    {
      button_change();
      wifi_button = false;
    }
    else
    {
      vTaskDelay(1);
    }
  }
}

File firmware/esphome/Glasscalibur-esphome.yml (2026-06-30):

# =============================================================================
# Glasscalibur — ESPHome firmware
# =============================================================================
#
# A Wi-Fi connected window-cover controller that drives a NEMA stepper motor
# via a TMC2209 driver, with physical end-stop limit switches at both ends of
# travel for absolute position calibration. Control it via a browser at
# http://glasscalibur-XXXXXX.local (where XXXXXX is the last 3 bytes of the
# device's MAC, printed on the serial log at boot). No Home Assistant
# required. Can also pair with Home Assistant over the native ESPHome API.
#
# -----------------------------------------------------------------------------
# Hardware
# -----------------------------------------------------------------------------
#   MCU       : ESP32-C6-MINI-1 (esp-idf framework, USB-Serial-JTAG console)
#   Driver    : TMC2209 stepper driver, single-wire UART control (PDN_UART)
#   Motor     : NEMA stepper, 8x microstepping = 1600 steps/rev
#   End stops : two physical limit switches (one at each end of travel)
#   Sensors   : TMP1075 motor temperature (I2C 0x49) — auto-stops at >80 °C
#               LIS2DH12 accelerometer (I2C 0x19) — anti-tamper + vib stall
#   Buzzer    : passive piezo on a ledc PWM output (tamper alarm)
#
# -----------------------------------------------------------------------------
# GPIO wiring
# -----------------------------------------------------------------------------
#   GPIO0  : UART RX   <- TMC2209 PDN_UART
#   GPIO1  : UART TX   -> TMC2209 PDN_UART
#   GPIO3  : Close-end limit switch (active low, polled)
#   GPIO5  : Buzzer (ledc output)
#   GPIO6  : INDEX     (TMC2209 step-counter output, informational)
#   GPIO8  : ENN       (TMC2209 enable, active low)
#   GPIO14 : DIAG      (TMC2209 StallGuard / fault output -> on_stall)
#   GPIO15 : Open-end limit switch (active low, polled)
#   GPIO21 : Wi-Fi Reset button (active low; hold 3-10 s to clear creds)
#   GPIO19 : I2C SDA
#   GPIO20 : I2C SCL
#   GPIO23 : Button 1 (active low; single/double click)
#
# -----------------------------------------------------------------------------
# Position / motion model
# -----------------------------------------------------------------------------
#   Steps are the canonical position unit. The cover entity reports position
#   as a 0..1 ratio of current_position / max_distance_steps:
#
#       position = current_position / max_distance_steps     (0.0 .. 1.0)
#
#   max_distance_steps is a compile-time substitution (see `substitutions:`
#   below) that defines the full travel between limits. Hitting a limit
#   switch re-calibrates the stepper to a known absolute position (0 at the
#   close end, max_distance_steps at the open end), correcting any drift.
#   Position is persisted to flash at every IDLE transition so the cover
#   survives reboots without re-homing.
#
# -----------------------------------------------------------------------------
# State machine (global_state, mirrored to the "State" text_sensor)
# -----------------------------------------------------------------------------
#   0 = IDLE      no motion in progress
#   1 = OPENING   driving toward max_distance_steps
#   2 = CLOSING   driving toward 0
#   3 = TAMPERED  tamper detected; alarm active or pending acknowledgement
#
#   OPENING/CLOSING return to IDLE via the 200 ms motion-completion poll,
#   any cover stop_action (limit switch, temperature cutoff, manual stop),
#   or the TMC2209 on_stall handler. TAMPERED is a *soft indicator* —
#   subsequent motion commands override it; it only returns to IDLE on
#   explicit acknowledgement (Button 1 single-click, "Clear Tamper Alert",
#   or "Set Tamper Baseline").
#
# -----------------------------------------------------------------------------
# Buttons (physical, on the device)
# -----------------------------------------------------------------------------
#   Button 1 (GPIO23):
#     - Single click  : TAMPERED        -> silence alarm + return to IDLE
#                       OPENING/CLOSING -> stop motor
#                       IDLE            -> close the cover
#     - Double click  : open the cover
#   WiFi Reset (GPIO21):
#     - Hold 3-10 s   : clear saved Wi-Fi credentials and reboot into setup
#
# -----------------------------------------------------------------------------
# Anti-tamper (accelerometer-based)
# -----------------------------------------------------------------------------
#   The LIS2DH12 establishes a "rest orientation" baseline. While IDLE, a
#   1 s interval compares live x/y/z to the baseline; if Euclidean distance
#   exceeds the Tamper Threshold, the device enters TAMPERED state, latches
#   "Tamper Detected", and pulses the buzzer for 60 s. The alarm dismisses
#   via Button 1 single-click, "Clear Tamper Alert", or "Set Tamper Baseline"
#   (which also captures a new baseline at the current position).
#
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

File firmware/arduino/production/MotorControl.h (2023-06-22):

uint16_t positionLabel;

#include "soc/timer_group_struct.h"
#include "soc/timer_group_reg.h"

#define STEP_PIN  17
#define DIR_PIN  16
#define ENABLE_PIN 27

#define RXD2 19
#define TXD2 21
#define STALLGUARD 18
#define SENSOR1 34
#define SENSOR2 35

#define BUTTON2 22
#define BUTTON1 23

#define SCK 32
#define MISO 14
#define MOSI 33
#define nCS 15

#define SHAFT true

#define SERIAL_PORT_2    Serial2    // TMC2208/TMC2224 HardwareSerial port
#define DRIVER_ADDRESS   0b00       // TMC2209 Driver address according to MS1 and MS2
#define R_SENSE          0.10f      // E_SENSE for current calc.  

FastAccelStepperEngine engine = FastAccelStepperEngine();
FastAccelStepper *stepper = NULL;
TMC2209Stepper driver(&SERIAL_PORT_2, R_SENSE , DRIVER_ADDRESS);
MagneticSensorMT6835 sensor = MagneticSensorMT6835(nCS);

void IRAM_ATTR button1pressed()
{
  //move_to_step = 0;
  //run_motor = true;
  btn1Press = 1;
}

void IRAM_ATTR button2pressed()
{
  //move_to_step = max_steps;
  //run_motor = true;
  btn2Press = 1;
}

void IRAM_ATTR stalled_position()
{
  stalled_motor = true;
  stop_motor = true;
}

void IRAM_ATTR sensor_short()
{
  sensor2_trip = true;
}

void IRAM_ATTR sensor_long()
{
  sensor1_trip = true;
}

void IRAM_ATTR wifi_button_press()
{
  wifi_button = true;
}

void move_motor() {
  Serial.print("Current Position: ");
  Serial.println(current_position);

  Serial.print("Moving to Position: ");
  Serial.println(move_to_step);

  stepper->setCurrentPosition(current_position);

  stalled_motor = false;
  sensor1_trip = false;
  sensor2_trip = false;

  stepper->setAcceleration(accel);
  stepper->setSpeedInHz(max_speed);
  driver.rms_current(current);
  driver.SGTHRS(stall);
  driver.TCOOLTHRS(tcools);


  if (move_to_step == 0)
  {

    Serial.println("Closing until Trip");
    stepper->moveTo(-one_inch * 25);
    motor_running = true;

    while (stepper->getCurrentPosition() != stepper->targetPos())
    {
      if (sensor1_trip == true || (digitalRead(SENSOR1) == LOW))
      {
        printf("TRIPPED ON 1\n");
        stepper->forceStop(); // Stop as fast as possible: sets new target
        delay(100);
        stepper->setCurrentPosition(0);
        stepper->moveTo(0);
      }

      if (stalled_motor == true)
      {
        printf("Stalled\n");
        stepper->forceStop(); // Stop as fast as possible: sets new target
        delay(100);
        stepper->moveTo(stepper->getCurrentPosition());
      }

      vTaskDelay(1);
    }
  }
  else if (move_to_step > current_position) // Open
  {

    Serial.println("Opening");
    stepper->moveTo(move_to_step);
    motor_running = true;

    while (stepper->getCurrentPosition() != stepper->targetPos()) {

      if (sensor2_trip == true || digitalRead(SENSOR2) == LOW)
      {
        printf("TRIPPED ON 2\n");
        stepper->forceStop(); // Stop as fast as possible: sets new target
        delay(100);
        stepper->setCurrentPosition(max_steps);
        stepper->moveTo(max_steps);
      }

      if (stalled_motor == true)
      {
        printf("Stalled\n");
        stepper->forceStop(); // Stop as fast as possible: sets new target
        delay(100);
        stepper->moveTo(stepper->getCurrentPosition());
      }

      vTaskDelay(1);

    }
  }
  else if (move_to_step < current_position)
  {

    Serial.println("Closing");
    stepper->moveTo(move_to_step);
    motor_running = true;

    while (stepper->getCurrentPosition() != stepper->targetPos())
    {

      if (sensor1_trip == true || (digitalRead(SENSOR1) == LOW)) //(sensor1_trip == true) ||
      {
        printf("TRIPPED ON 1\n");
        stepper->forceStop(); // Stop as fast as possible: sets new target
        delay(100);
        stepper->setCurrentPosition(0);
        stepper->moveTo(0);
      }

      if (stalled_motor == true)
      {
        printf("Stalled\n");
        stepper->forceStop(); // Stop as fast as possible: sets new target
        delay(100);
        stepper->moveTo(stepper->getCurrentPosition());
      }

      vTaskDelay(1);
    }
  }
  else if (current_position == move_to_step)
  {
    Serial.println("ALREADY THERE!");
  }
  else
  {
    Serial.println("DO NOTHING!");
  }
  motor_running = false;
  current_position = stepper->getCurrentPosition();
  printf("Motor Function Complete\n");
}

// put your setup code here, to run once:
void setup_motors() {

  pinMode(ENABLE_PIN, OUTPUT);
  pinMode(DIR_PIN, OUTPUT);
  pinMode(STEP_PIN, OUTPUT);
  pinMode(STALLGUARD , INPUT);
  pinMode(WIFI_PIN , INPUT);

  pinMode(SENSOR1, INPUT);
  pinMode(SENSOR2, INPUT);

  pinMode(BUTTON1, INPUT);
  pinMode(BUTTON2, INPUT);

  SERIAL_PORT_2.begin(115200);

  driver.begin();
  driver.toff(4);
  driver.blank_time(24);
  driver.I_scale_analog(false);
  driver.internal_Rsense(false);
  driver.mstep_reg_select(true);
  driver.rms_current(current);
  driver.SGTHRS(stall);
  driver.microsteps(motor_microsteps);
  driver.TCOOLTHRS(tcools); //
  driver.TPWMTHRS(0);
  driver.semin(0);
  driver.shaft(SHAFT);
  driver.en_spreadCycle(false);
  driver.pdn_disable(true);

  engine.init();
  stepper = engine.stepperConnectToPin(STEP_PIN);
  stepper->setDirectionPin(DIR_PIN);
  stepper->setEnablePin(ENABLE_PIN);
  stepper->setAutoEnable(true);

  attachInterrupt(STALLGUARD, stalled_position, RISING);
  attachInterrupt(WIFI_PIN, wifi_button_press, FALLING);
  attachInterrupt(BUTTON1, button1pressed, FALLING);
  attachInterrupt(BUTTON2, button2pressed, FALLING);
  attachInterrupt(SENSOR1, sensor_long, FALLING);
  attachInterrupt(SENSOR2, sensor_short, FALLING);
}

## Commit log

2022-06-17 Updated STLs
    [MH1.3mf, MH10.3mf, MH11.3mf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]
2022-06-24 STLs fix
    [MH1.3mf, MH10.3mf, MH11.3mf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]
2022-07-09 UPdate platter
    [Model-H-1.3mf]
2026-05-11 Refactor ESPHome configuration for Glasscalibur: add global_tcoolthrs, update max_distance_revs format, enhance logging, and improve motor stall handling.
    [Glasscalibur-esphome.yml]
2026-06-09 Add Glasscalibur ESPHome firmware config
    Add ESPHome firmware for the Glasscalibur window-cover controller and a .gitignore. The YAML includes external components (TMC2209 driver, LIS2DH12 accel), persistent globals, stepper/TMC2209 configuration, UART/I2C setup, web_server and provisioning (captive portal / improv_serial), OTA, and project identity with dynamic MAC-based name. Features added: accelerometer-based anti-tamper (baseline, threshold, alarm script, clear/set buttons), vibration-based stall detection (debounced), StallGuard handling, motion-completion polling and position persistence, schedule/timezone controls, diagnostic sensors and lifetime counters, WiFi reset button, and seve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
    [Glasscalibur-esphome.yml]
2026-06-09 Add test esphome config; WiFi reset -> GPIO21
    Add a new minimal, no‑WiFi hardware-test ESPhome config (firmware/esphome/Glasscalibur-esphome-test.yml) for PCB bring-up. The test build boots on ESP32-C6 (esp-idf), chirps the buzzer on boot, scans I2C, exercises the TMC2209 stepper, logs LIS2DH12 accel and TMP1075 motor temperature, and maps buttons/limit switches for manual verification. Also update the main config (firmware/esphome/Glasscalibur-esphome.yml) to repurpose the WiFi Reset button from GPIO17 to GPIO21 (documentation and pin setting) to match the revised pinout.
    [Glasscalibur-esphome-test.yml, Glasscalibur-esphome.yml]
2026-06-12 Enhance LIS2DH12 feedback documentation: prioritize main loop blocking fixes, expose hardware interrupts, and improve logging
    [Glasscalibur-esphome.yml]
2026-06-22 New plastics
    [MH1.3mf, MH10.3mf, MH11.3mf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]
2026-06-30 firmware v1.1.0: GitHub OTA update button, sun schedule, grouped web UI
    - ota: add http_request platform + "Update Firmware (GitHub)" button that
    pulls the latest release from GitHub and self-flashes; add a "Firmware
    Version" diagnostic sensor and a "Restart" button.
    - web_server v3: organize every entity into Control / Motion Tuning /
    StallGuard / Security-Tamper / Schedule / Diagnostics groups.
    - schedule: add sunrise/sunset mode (latitude/longitude + signed minute
    offsets, "Sun Schedule" switch, 60s sun poll); fixed Open/Close-Time
    triggers are suppressed while Sun Schedule is on.
    - bump firmware_version 1.0.0 -> 1.1.0; rewrite stale esphome README to
    document the features and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
    [Glasscalibur-esphome.yml]
2026-06-30 esphome test: point at Valar-Systems LIS2DH12 fork
    Match the production YAML — both now resolve LIS2DH12 from
    github://Valar-Systems/esphome-lis2dh12 instead of latonita's
    pinned SHA.
    [Glasscalibur-esphome-test.yml]
2026-06-30 Move Arduino firmwares under firmware/arduino/; update platter STL
    Relocate the legacy Arduino-based firmwares from
    firmware/{Glasscalibur-simple,production} to firmware/arduino/
    so they sit alongside firmware/esphome/ under a consistent
    per-framework parent directory. Pure rename, no code changes.
    Also includes an updated hardware/v2.0/platter-v1.3mf.
    [platter-v1.3mf]
2026-06-30 README: full rewrite for ESPHome firmware
    The README described the legacy Arduino build (HTTP control, hall-effect
    sensors, old hardware layout). Rewrite it for the current ESP32-C6 + TMC2209
    ESPHome firmware: browser/Home Assistant/REST control, StallGuard + vibration
    stall + over-temp + anti-tamper safety, built-in scheduling, GitHub OTA
    updates, updated repo layout and hardware/v2.0 3D-print paths, and links to the
    rewritten wiki. Product/marketing copy (use cases, kits, fit guidance) kept.
2026-07-07 firmware v1.2.0: add Child Lock switch
    Adds a Child Lock switch (Control group) that disables the physical
    Button 1 (single- and double-click) while leaving web UI, Home Assistant,
    and the open/close schedule fully functional, so the cover can still be
    operated and the lock toggled remotely. The Wi-Fi-reset button is left
    active so the device can always be recovered. State persists across
    reboots and defaults OFF.
    Bump firmware_version 1.1.0 -> 1.2.0 and add CHANGELOG.md.
2026-07-14 firmware v1.3.0: field-validated auto-calibration overhaul
    - Single-pass escalating calibration: home at irun 19, then one open +
    one close leg walking the {12,15,17,19} current ladder in place;
    limit switches remain the only success oracle
    - Fix accelerometer units (sensor publishes m/s^2, thresholds are g)
    in the vibration stall detector and tamper check
    - Ramp-aware launch masks, leaky SG-starvation counter, +2/-1 vibration
    counter; per-leg tune accumulators with an arrival-gap sampler gate
    - Derive SGTHRS (SGmin/4), TCOOLTHRS (1.5x measured cruise TSTEP) and
    vibration threshold (3x free-run max) from the run; StallGuard is
    armed at operating speed for the first time
    - Thermal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
2026-07-22 firmware: rewire onto valar-core v0.3.0 + scheduling packages
    Refactor the 2939-line monolith into a board wrapper + product layer that pull
    the shared valar-core (v0.3.0) and scheduling mixin as packages, keeping only
    Glasscalibur's product hardware and logic in glasscalibur-product.yaml.
    Board wrapper (Glasscalibur-esphome.yml): chip, GPIO map, OTA identity, and the
    stepper_* / motor_direction_default substitutions that express Glasscalibur's
    220 mOhm / inf-decel / counter-clockwise hardware against core's defaults.
    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
2026-07-22 firmware: pin core v0.3.0 remote packages, add build CI + v2.0.0 changelog
    - Board wrapper now pulls valar-core + scheduling from Valar-Systems/valar-motion
    at ref v0.3.0 (remote packages) instead of dev-time local includes. Config
    re-validated against the released tag; regression gate unchanged.
    - Add .github/workflows/build-release.yml (mirrors the Ropener pipeline, single
    board): compiles on push/PR, and on a v* tag stamps fw_version from the tag and
    attaches Glasscalibur.factory.bin / .ota.bin / .ota.bin.md5 to the release.
    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
2026-07-22 firmware: reorganize web UI groups (Ropener-style), split Stall Detection
    Vibration-based stall detection is an accelerometer feature, not StallGuard, so
    give it its own "Stall Detection" group. Demote the TMC2209 StallGuard controls
    to an advanced group at the very bottom (as on the Ropener), and pull the
    SG_RESULT/TSTEP readouts down into it.
    Page order is now: Control, Motion Tuning (Speed/Accel/Motor Current),
    Calibration (Auto-Calibrate + status), Stall Detection (vibration), Schedule,
    Security/Tamper, Diagnostics, StallGuard (advanced) — SGTHRS/TCOOLTHRS/SG_RESULT/
    TSTEP/enable. Uses product-local groups and !extend to move core entities,
    leaving core's group_motion/group_stallguard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
2026-07-22 firmware: friendly Motor Current (mA) + Motion Tuning directly under Control
    - Add a "Motor Current" number in milliamps to Motion Tuning, driven by the
    driver's own read_run_current_mA / write_run_current_mA (no hand formula). Capped
    at 600 mA = IRUN 19, this motor's thermal ceiling. Keeps global_irun in sync.
    - Demote the raw IRUN register to "IRUN value" in the advanced StallGuard group
    for power users (still capped at 19).
    - Move the Motion Tuning group to weight 12 so it sits immediately under Control.
    Verified on hardware: Motor Current reads 538 mA at IRUN 17 (exact conversion).
2026-07-24 Change calibration gesture from double-click to 7 quick presses
    Auto-calibration drives the window through full travel, so the trigger
    must be hard to hit accidentally. The 3-10s Wi-Fi wipe hold on the same
    button is unchanged; timings still cannot overlap.
2026-07-24 feat(firmware): self-healing StallGuard auto-tune (opt-in)
    Continuously cross-check StallGuard against the accelerometer and nudge SGTHRS so
    the tune self-corrects between calibrations. New "StallGuard Auto-Tune" switch
    (advanced group, default OFF) gates it; requires StallGuard + Vibration Stall
    Detection both on.
    Two directions, both small (+/-1 register step), clamped, logged, and counted via
    a new "Auto-Tune Adjustments" diagnostic:
    - RAISE (high confidence): when the vibration detector trips (its sustained-judder
    threshold = a real stall) but StallGuard did NOT fire this travel, StallGuard was
    too insensitive -> SGTHRS += step (ceiling 60).
    - LOWER (conservative): a StallGuard trip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
2026-07-24 feat(firmware): friendly Slow/Medium/Fast speed presets (data-chosen), raise cap
    Add a "Speed" preset select (Motion Tuning) mapping Slow/Medium/Fast to
    1200 / 2600 / 5500 steps/s, and demote the raw Speed slider to the advanced
    group (mirrors the Ropener pattern). Raise stepper_max_speed 1200 -> 5500 so
    Fast is reachable.
    Values chosen from an accelerometer resonance sweep of this mechanism (external
    measurement tool, not shipped): vibration is flat and quiet across the range
    EXCEPT a violent drivetrain resonance at ~2900-3300 (worst 3000-3100, peak ~1 g).
    All three presets avoid parking in that band; ramps cross it only transiently,
    which measured harmless (clean position tracking). The m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
2026-11-04 Field fixes: reboots, calibration STOP, stall back-off, Obstruction event, update stop (#8)
    * predictions: field-hardening checks, written before any code
    Records the reviewer's rulings verbatim (one paragraph kept outside the
    repo at its own instruction), the R1f phase-by-phase statement, every
    check's predicted result and sabotage, the expected final gate output,
    and the bench plan. No check had been run when this was committed.
    * regression-gate: object IDs in the entity gate, no more anchor collisions
    The entity gate now prints each entity's object_id, computed with
    ESPHome's own get_base_entity_object_id, so a diff shows the ID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
2026-11-05 Learned open limit, end-of-travel faults, StallGuard on by default (2.2.0) (#9)
    * predictions: learned open limit (before any code)
    * predictions: Amendment 1 - self-review fixes registered before the code
    * firmware: learned open limit, end-of-travel targets and limit faults
    - The open switch (S4) position is learned per unit on an open that starts
    from a fresh close-switch (S5) home with no stall, accepted 94.0-101.0 mm,
    persisted only when it moves by more than 0.05 mm. New diagnostic sensor
    "Open stroke" (mm), logged on every open.
    - Open target = learned + 0.5 mm (1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
2026-11-05 Uncalibrated fail-safe: Fast speed until StallGuard is calibrated (2.2.0) (#10)
    * predictions: uncalibrated fail-safe (before any code)
    * firmware: uncalibrated fail-safe - Fast speed until StallGuard is calibrated
    - New persisted flag sg_calibrated, set only by a successful calibration and
    never cleared. Units calibrated by an earlier firmware are recognised at boot
    (cal_speed_at is only ever written by a successful run).
    - Until it is set, every move (open, close, Set-position, Button 1, schedules)
    runs at the Fast preset (speed_fast 5500), where the driver's default
    StallGuard threshold detects stalls. Calibration itself k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
2026-11-05 Run at the calibrated speed until a calibration at the new speed (2.2.0) (#11)
    * predictions: calibrated speed (before any code)
    * firmware: run at the calibrated speed until a calibration at the new speed
    - New persisted cal_speed: the speed the last successful calibration ran at
    (its StallGuard tune is only valid there). Set with the calibration; a
    failed calibration keeps it.
    - Units calibrated by older firmware take their saved speed setting as the
    calibrated speed at boot (logged).
    - One effective-speed expression for every speed setter: the setting during a
    calibration, Fast until calibrated, otherwise the calibrated sp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
2026-11-05 Older calibrations keep the speed they recorded (2.2.0) (#12)
    * predictions: recorded calibration speed (before any code)
    * firmware: older calibrations keep the speed they recorded
    A unit calibrated by older firmware now takes the speed that calibration
    recorded (cal_speed_at) as its calibrated speed, not the current setting. A
    setting changed since is an ordinary mismatch: moves run at the recorded speed,
    Speed Lock shows the notice and Calibration Status is STALE until a calibration
    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
2026-11-06 Remove the old design (kept at tag legacy-old-design) (#13)
    * Remove the old design (kept at tag legacy-old-design)
    Removes the Model-H Arduino firmware (firmware/arduino/), the old-design STEP
    files and print platter (hardware/v2.0/), the old Arduino setup guide
    (firmware/README.md) and media/ (old-mechanism GIFs and photos, and HA
    screenshots no kept doc references). All of it stays reachable at the
    legacy-old-design tag, which points at 2f3b357.
    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
2026-11-06 Split the firmware into local packages (no behaviour change) (#14)
    * predictions: split the firmware into local packages (before any code)
    * predictions: split Amendment 1 - interval order miss, re-registered
    * firmware: split the product into local packages (no behaviour change)
    firmware/glasscalibur.yaml (the board wrapper, moved from
    firmware/esphome/Glasscalibur-esphome.yml) stays the single entry file. The
    3,128-line glasscalibur-product.yaml becomes ten local packages in
    firmware/packages/: system, web-ui, motion, limits, faults, tamper, stall,
    calibration, temperature,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
2026-11-06 Rewrite the docs for the current design (#15)
    * predictions: docs rewrite (before any doc change)
    * docs: rewrite README.md and firmware/README.md for the current design
    README.md: what it is, how it works (current design), features, an install
    overview, the browser UI, Home Assistant and HTTP, updates, and links.
    firmware/README.md: layout, flashing and updates, first setup, the buttons,
    calibration and the speed lock, the learned open stroke, faults and what to
    do, stall detection and tamper, an entity reference and the pin map. It folds
    in firmware/esphome/README.md and Glasscalibur-auto-calibrate.md, which are
    removed. Every firm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
2026-11-06 Hardware v1.8 CAD (STEP and STL) under CERN-OHL-S-2.0 (#16)
    * predictions: hardware v1.8 CAD (before any file is added)
    * hardware: v1.8 CAD (STEP and STL) and CERN-OHL-S-2.0
    The printed, machined and extrusion parts of the v1.8 design (2026-11-05),
    copied byte for byte: one solid per STEP file, millimetres; binary STL files
    for the printed parts. hardware/.gitattributes stores CAD files without
    line-ending conversion. hardware/LICENSE is CERN's CERN-OHL-S-2.0 text.
    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
2026-11-06 README: store photos, sliding windows, kit, fit, power and opening by hand (#17)
    * predictions: README photos and confirmed facts (before any doc change)
    * docs: add the four store photos (metadata removed)
    * docs: README answers — sliding windows, kit, fit, power, manual opening
    - Intro: horizontal sliding windows; two store photos in the intro and How it works,
    two installed shots above Install overview.
    - Remove the mechanism-stop sentence; the stroke stays learned on each unit.
    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
2026-11-06 Hardware v1.8: carriage re-export (0.8 mm bumper-face trims) (#18)
    * predictions: v1.8 carriage re-export (before the files are replaced)
    * hardware: v1.8 carriage re-export (0.8 mm bumper-face trims)
    ---------
2026-11-06 Firmware: motor thermal protection and stall-detector interlock (2.2.0) (#19)
    * predictions: motor thermal protection and stall-detector interlock (before any code change)
    * firmware: motor thermal protection, stall-detector interlock, Tamper group
    - Thresholds as substitutions: warn 50, start gate 55, lockout 60, clear 48,
    no valid reading for 15 s = the same lockout (counted from boot).
    - Start gate first in the cover's open / close / position actions (every
    command path reaches the motor through them) and in auto_calibrate; STOP is
    never gated; a stall back-off already under way finishes.
    - Thermal Alert event (warning / loc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
2026-11-06 Firmware: refused scheduled moves wait for the motor to cool; Thermal Alert "refused" (2.2.0) (#20)
    * predictions: thermal follow-ups (before any code change)
    * predictions: thermal follow-ups, Amendment 1 (R1 stop fact re-registered)
    * firmware: refused scheduled moves wait for the motor to cool; Thermal Alert "refused"
    - A scheduled open / close the thermal start gate refuses is kept pending (a
    later refused one replaces it) and runs once the motor reads below 50 C with
    the gate open, within 30 min; otherwise it is dropped and logged. A later
    accepted command or a STOP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
2026-11-06 Bench: automatic TP-1 (test build, run script, simulator) (#23)
    * predictions: automatic TP-1 (bench tooling and expected results, before the tooling)
    * predictions: automatic TP-1, Amendment 1 (heat by Slow strokes; heater as fallback)
    * predictions: automatic TP-1, Amendment 2 (B2 re-registered)
    * bench: automatic TP-1 — test build, test package, run script and simulator
    Bench only, never released. glasscalibur-tp1.yaml = the bench build plus tp1-bench.yaml
    (motion backstop at 62 C, fallback hold-current heater with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
2026-11-07 Bench: simulated dead limit switch, find the unit by MAC, F5 note (#24)
    * predictions: bench dead-switch simulation for L3/L4; F5 note (F6 supersedes its last sentence)
    * bench: simulated dead limit switch (S4 / S5) for L3 and L4
    Two BENCH switches, default off. While one is on, its limit sensor reads released whatever
    the pin does; the filter is appended after the product's own filters. Bench build only.
    * predictions: dead-switch note — the schematic confirms a broken switch reads released
    * predictions: automatic T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
2026-11-07 Firmware: limit-switch inputs use the internal pull-up (2.2.0) (#25)
    * predictions: limit-switch inputs, internal pull-up (before any code change)
    * firmware: limit-switch inputs use the internal pull-up
    GPIO15 (S4) and GPIO3 (S5) keep the board's pull-up and gain the chip's, so a broken link
    between a switch and the chip reads released instead of floating. Pin map and CHANGELOG
    updated.
    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
2026-11-07 Bench: guard opens until the stroke is learned; TP-1 needs a learned stroke (#26)
    * predictions: bench open guard until the stroke is learned; TP-1 Amendment 4
    * bench: guard opens until the stroke is learned; TP-1 needs a learned stroke
    open_guard.py (MAC-checked, sends only STOP) stops an open that passes 97 mm without S4, or
    that starts with no S5 reference, while Open stroke is unknown. tp1_run.py stops before its
    first command unless Open stroke is learned, and no longer restores when it changed nothing.
    tp1_sim.py models the carriage in mm with both switches, the learned stroke and the old
    carriage's hard stop.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
2026-11-11 Bench: window-end guard; trimmed-carriage guard limit (#29)
    * predictions: bench window-end guard and trimmed-carriage guard limit
    * bench: window-end guard (tp1_run, open_guard); trimmed-carriage guard limit
    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
